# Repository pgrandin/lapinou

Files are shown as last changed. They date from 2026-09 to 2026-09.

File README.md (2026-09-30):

# Lapinou — side-view growth timelapse planter

Python-generated CadQuery assembly for a Raspberry Pi 3B+, provisionally using Camera Module 3 **standard**. The camera, Pi and provisional LED puck references are imported from STEP. The pot provides a **50.8 mm internal diameter × 76.2 mm usable depth** (2 × 3 inches). Default framing allows a **127 mm tall × 127 mm wide** plant (5 inches), with the camera level and 250 mm from the stem plane by default. Five indexed positions provide **230, 250, 270, 290 and 310 mm** camera-to-stem distances using the same printed parts.

This is a working prototype with printed parts and a tested 1.7 mm M2 camera pilot-hole coupon. The deployed camera runs on a **Pi 2 Model B Rev 1.1 with an IMX219 sensor and USB Wi-Fi**. The CAD electronics references still show a Pi 3B+ and Camera Module 3 standard; their full envelopes and optical framing have not been updated to match the deployed hardware. The Pi reference is a simplified community model; mounting-hole positions were checked against Raspberry Pi's official drawing.

## Quick start

```bash
git clone https://github.com/pgrandin/lapinou.git
cd lapinou
python3 -m http.server 8765 --directory viewer
```

Hosted on the homelab at http://lapinou.lab.lan (redeploy with `lab deploy . --name lapinou`; see `Dockerfile`).

Open http://localhost:8765/ for the assembly or http://localhost:8765/#bed for the print layouts. Current individual STEP/STL parts and viewer assets are included. The large complete `output/assembly.step` download is generated locally with the commands below; it is not committed. `output/printed_assembly.step` contains the printed parts only.

The minimal camera daemon and Frigate example are in `pi-camera/`. It serves a changing JPEG and archives a snapshot every six hours. See `pi-camera/README.md` for installation and service commands. No camera photographs, credentials, or printer upload scripts are included.

## Files

- Generator: `generate.py`
- Complete assembly, with imported electronics: `output/assembly.step`
- Printed parts in assembly positions: `output/printed_assembly.step`
- Eleven individual parts (nine original plus two light-mount additions), each as STEP and STL in print orientation: `output/print/`
- Actual CAD preview: `output/assembly.png`
- Geometry and mesh checks: `output/validation.json`
- Reference provenance: `references/SOURCES.md`

STEP preserves editable solids and assembly positions; the Python file is the parametric source. Do not slice the complete assembly: it includes electronics references, and the parts need separate print orientations.

## Regenerate

Interactive browser viewer: http://localhost:8765/

Direct print-bed view: http://localhost:8765/#bed.

Serve the viewer locally or on your LAN:

```bash
python3 -m http.server 8765 --bind 0.0.0.0 --directory viewer
```

The viewer includes orbit/pan/zoom, side/top views, five selectable camera distances, part visibility, an exploded view and STEP/STL downloads. The STEP download is the generated default 250 mm assembly; changing the viewer selector moves the displayed assembly only. Individual printed parts work at every position. Three.js 0.180.0 and its MIT licence are stored locally in the viewer's vendor directory; no CDN is needed at runtime. The viewer shares geometry between assembly and bed modes, batches renders to one per animation frame, and uses lightweight lighting with a capped pixel ratio. Only display meshes load at startup; full-detail print STLs download on request. Electronics display meshes are simplified to approximately 15,000 triangles where needed; the original STEP imports and manufactured geometry remain full detail. The generator also writes display meshes and a manifest to `output/web/`. Relative symlinks connect those files and downloads to the viewer. For an alternative generator output directory, update those links before serving it.

Browser smoke check (regenerate the full assembly STEP first; requires Node.js):

```bash
# Run from the repository root
npm install --prefix scratch/web-test playwright
./scratch/web-test/node_modules/.bin/playwright install chromium
NODE_PATH=./scratch/web-test/node_modules node viewer/smoke.cjs
```

```bash
# Run from the repository root
uv venv .venv --python 3.12
uv pip install --python .venv/bin/python -r requirements.txt
.venv/bin/python generate_puck.py
.venv/bin/python generate.py
```

Change framing, for example:

```bash
.venv/bin/python generate.py --plant-height 150 --plant-width 100 --distance 290 --output output-150mm
```

Dimensions are millimetres. The distance argument selects an assembly position from 230/250/270/290/310; it does not change the printed parts. Changing plant height changes the mast, ruler and light-arm geometry. Supported ranges are limited to what the two-piece base and ruler placement support. Changing the camera model requires adapting its STEP transformation, mounting pattern and field-of-view calculation. It is not interchangeable merely because a replacement STEP imports successfully.

## Mechanical design

| Part | Function |
| --- | --- |
| camera_base | Rigid rail, mast foot mounting and four 12 mm tall Pi supports |
| plant_base | Matching rail, pot platform and ruler support mounting |
| catch_tray | Drainage basin wrapping around the pot ears; blind fixing holes keep the floor closed |
| pot | 2.4 mm walls, 3.2 mm floor, five 3 mm drainage holes, and two retaining ears flush with the pot bottom |
| camera_mast | Flat camera plate with four bosses and ribbon tie slots |
| camera_shoe | Low socket bolted to the existing camera-base holes; clamps the camera plate |
| ruler_support | Flat plate connecting the ruler to its mounting shoe |
| ruler_shoe | Low open channel bolted to the existing plant-base holes |
| growth_ruler | Raised 5 mm graduations and bold 50 mm labels; two screws prevent rotation |
| light_arm | New flat-printing arm behind the ruler; uses its existing two holes |
| light_cradle | New annular puck seat with three washer retainers and clear LED opening |

The two base halves use an indexed lap with **40–120 mm overlap**, depending on position. The moving upper plate has six columns of 3.3 mm clearance holes at 20 mm pitch, in two rows. The fixed lower plate has four **2.6 mm pilot holes** for M3 screws driven directly into PLA. Use all four screws, from above, through two adjacent columns. Each engraved distance label lies between its selected columns. There are no nuts on this joint. The lower plate provides 4 mm of plastic thread engagement; the upper plate clears the screw so tightening clamps the two halves together. Two short screws retain the pot on the tray; two separate screws retain the tray on the base. The camera's four M2 holes use a 21 × 12.5 mm pattern taken from the imported STEP. The Pi's four M2.5 holes use the 58 × 49 mm pattern confirmed in the manufacturer drawing.

Both mounts now separate into a flat plate and a low shoe. The camera plate seats 24 mm into a socket, with 0.4 mm clearance in front and 0.2 mm at each side. The ruler support seats in a 24 mm deep open channel with 0.4 mm clearance in front. Two M3 × 12 mm screws per shoe pass through 3.3 mm clearances and grip 2.6 mm pilots in the plate, with nominal 4 mm thread engagement and no nuts. Tightening pulls each plate onto its rear datum. The camera lens, ruler face, soil zero and base mounting-hole positions remain at their previous coordinates. The ruler shoe has a narrow rear post to leave the foot nuts accessible.

Exposed edges are softened in the Python model:

- Main base and mast-foot corners: 3 mm radii with 0.5 mm perimeter bevels.
- Pot lip: 0.8 mm fillet; tray lip: 0.6 mm fillet; pot ears have 2 mm corner radii and 0.5 mm bevels.
- Flat plates and ruler: 1–1.5 mm corner radii, with 0.3–0.5 mm edge bevels. Shoe walls have 0.3–2 mm corner radii and 0.2–0.4 mm top bevels.
- Cable slots: 0.8 mm rounded corners and 0.3 mm entry/exit bevels.

Pot ears use 3.3 mm clearance holes and the tray uses 2.6 mm blind pilots. Other mounting holes retain their specified diameters: 3.4 mm for the remaining M3 printed-part joints, 2.8 mm for Pi M2.5 screws, with nuts. The four camera bosses now use 1.7 mm pilots for M2 screws biting directly into PLA, without nuts. Camera hole spacing remains 21 × 12.5 mm; the bosses and bracket outline are unchanged. Clamping surfaces stay planar and the base lap faces remain square. The ruler has a 2 mm margin below zero and its ticks start 1 mm in from the side to keep the raised markings supported behind the perimeter bevel. Its print footprint is now 134 × 24 mm, with the same 3.0 mm body and 0.8 mm relief.

The pot, tray and ruler move as one assembly when the distance changes. The Pi and camera stay together, so adjustment does not change the ribbon route. Remove the four joint screws, move the plant half to the selected holes, and tighten on a flat surface. Hole clearance and printer tolerance limit repositioning accuracy; check focus and recalibrate pixels/mm after changing distance. Keep the distance fixed during each timelapse.

The Pi mounts on the open, elevated platform at the camera end, approximately 200 mm away from the pot. Ports remain accessible. This is an indoor open carrier, not a sealed or splashproof enclosure. No HAT or heatsink is included in the clearance checks.

The pot bottom and its two retaining ears share the same flat underside at assembly Z = 14.4 mm. The ears print directly on the bed, with 6 mm thickness and rounded, bevelled edges. The tray wall follows around both ears with 0.6 mm clearance; its footprint is 80 × 104 mm. Four internal pads and two ear pads support the pot. Two M3 × 10 mm screws enter from above through the ears at Y = ±38 mm. Two more enter from below the base at the existing Y = ±44 mm holes. Each screw engages a separate 4.2 mm deep blind pilot in the tray, with a 2.2 mm closed end. Use no washer on these four screws; nominal engagement is 4 mm. Remove the top two screws to lift out the pot. Water in place during recordings to preserve registration. Check the printed tray for leaks before mounting powered electronics and avoid filling it high enough to submerge the pot floor.

## Hardware and assembly

Use button-head screws for the recessed underside locations; check actual head dimensions against the 6.6 mm diameter × 2 mm deep recesses. No heat-set inserts or printed threads are required.

| Fastener | Qty | Location |
| --- | ---: | --- |
| M3 × 8 mm self-tapping/thread-forming screw, no nut | 4 | Adjustable base lap; screws enter from above into PLA pilots |
| M3 × 16 mm button head, nut, washer | 8 | Camera and ruler shoe feet; from below |
| M3 × 12 mm self-tapping/thread-forming screw, no nut | 4 | Two per shoe, entering from the back into the flat plate |
| M3 × 10 mm self-tapping/thread-forming screw, no nut | 4 | Two below the base into the tray; two above the pot ears into separate tray pilots |
| M3 × 20 mm, nut, thin washer | 2 | Ruler + support + new light arm; replaces the original M3 × 12 screws |
| M3 × 10 mm self-tapping/thread-forming screw, no nut | 2 | Light cradle to arm |
| M3 × 6 mm self-tapping screw, 9 mm OD M3 washer | 3 | Puck rim retention |
| M2.5 × 25 mm button head, nut, nylon washer | 4 | Pi mounting posts; from below |
| M2 × 8 mm, small nylon washer, no nut | 4 | Camera; screws enter from the camera side and bite into 1.7 mm PLA pilots |

Print `output/print/m3_pilot_coupon.stl` in the same PLA and settings as the base first. It has labelled 2.5, 2.6 and 2.7 mm pilots through a 4 mm plate, matching the threaded lap thickness. Use the actual screws to find a firm fit without splitting or stripping. The default is 2.6 mm; change `JOINT_PILOT` in `generate.py` and regenerate if needed. The lap uses 8 mm screws with an 8 mm stack and no washer; check that the actual tip does not protrude below the base. A pointed tip gives less full-thread engagement. Tighten by hand; repeated removal can wear PLA threads. The mount clamps and blind tray fixings also use this pilot size; the remaining joints use the nuts listed above.

Dry-assemble before final tightening; screw lengths assume ordinary nuts and thin washers. Tighten PCB hardware gently. Fasteners, washers and the ribbon cable are described here but are not separate CAD objects.

For an M2 screw fit check before reprinting the camera plate, run `.venv/bin/python generate_camera_fit.py` after generating the assembly. This crops all four camera bosses directly from the print-oriented STEP, preserving the 1.7 mm pilots, 21 × 12.5 mm spacing, 7 mm backing and 4.38 mm bosses. The test piece is 20.5 × 29 mm and prints back down using the same settings as the full plate. Files: `output/print/camera_mount_fit.stl` and `output/print/camera_mount_fit.step`. Check screw grip and camera alignment on this piece before printing the full mount.

1. Select the 250 mm index initially and screw the two rails together on a flat surface using all four M3 screws from above. Bolt both mounting shoes to their existing base holes, seat the small pilot-hole ends of both flat plates fully on the shoe floors, then install two M3 × 12 mm clamp screws per shoe from behind. Use no washer under these clamp heads; the 12 mm length allows 4 mm nominal engagement after the 8 mm shoe wall.
2. Fit the Pi to its mounting posts and fit the camera to the mast's four front bosses, lens pointing at the pot. Insert the four M2 × 8 screws through small nylon washers and the camera PCB into the 1.7 mm PLA pilots. Tighten gently by hand. The pilot is a starting print fit; adjust `CAMERA_PILOT` in `generate.py` if the actual screws fit too tightly or loosely. An already printed bracket with 2.3 mm through-holes can still use the original M2 × 16 screws and nuts; direct PLA engagement requires the revised camera plate.
3. Route a **15-pin to 15-pin, 1 mm pitch CSI cable** from the camera, over the mast and down its back to the Pi. A 300 mm cable is a starting length; confirm the route with string and allow relaxed bends. The 200 mm stock cable may be short. Sleeve the cable where it is loosely restrained by ties; do not pinch its conductors or sharply fold it.
4. Attach the tray from below with two M3 × 10 mm screws, then seat the pot and secure its ears from above with two more M3 × 10 mm screws. Install the ruler with the raised markings toward the camera.
5. Fill soil to the small marks **3 mm below the rim**. The ruler's zero corresponds to that height. Lock the setup before recording.

## Printing

All exported STLs are translated to the bed and oriented individually. The plant base is **220 × 158 mm** and the camera base is **215 × 150 mm**. Both fit the MK3’s 250 × 210 mm bed with their long dimension along X. Allow for your printer's actual printable area and brim requirements.

Use **Bed** in the viewer to inspect five production plates and a separate pilot coupon test. It reuses lightweight display meshes with the same print rotations generated for the STL exports, excludes electronics, and provides Orbit/Side/Top views. The plate selector shows each part's XYZ dimensions, lower-left X/Y position in millimetres, and its STL download. Each layout leaves at least 5 mm at the bed edges and 10 mm between part bounding boxes, with Z = 0 at the bed and all parts below the MK3's 210 mm height limit. The grid is 10 mm; the dashed rectangle marks the 5 mm edge margin.

| Plate | Parts and orientation |
| --- | --- |
| 1 | Camera base, base down and Pi posts up |
| 2 | Plant base, top face down to support the long lap |
| 3 | Pot and tray upright; camera and ruler support plates flat; both low shoes base down |
| 4 | Ruler only, flat with markings up for the colour change |
| 5 | New light arm flat and puck cradle shelf down; existing prints reused |
| Test | Pilot coupon; print this before the bases |

For the default 5-inch plant, the camera plate prints **158.3 × 38 × 11.38 mm**, the ruler support **96.8 × 24 × 5 mm**, and the two shoes are **30 mm high**. The third plate now tops out at the pot’s 79.4 mm instead of the previous 164.3 mm camera mast. Actual print-time savings depend on slicing settings; no time estimate is claimed. A different plant height may require rearranging the plate; the viewer flags insufficient spacing.

These are layout previews, not sliced jobs. STL downloads remain individual parts at their own origins; use the displayed positions to reproduce a plate in PrusaSlicer. Add local supports and any brims in the slicer and inspect their clearance. Print the grouped parts by layer rather than sequentially completing each object. The colour change applies only to the ruler plate.

- PLA is the starting material for the self-tapping joint. Start with a 0.4 mm nozzle, 0.2 mm layers, 4–5 walls, 5–6 top/bottom layers and 30–40% infill. These are untested starting settings.
- Pot, tray, camera base and the two low shoes print base down. The camera plate prints back down with bosses facing up; the ruler support plate prints flat. The plant base prints upside down with its broad top and upper lap on the bed; this avoids a long unsupported tongue. Its engraved distance labels face the bed. The ruler prints flat, raised markings up.
- The pot ears lie flush with the bottom and print directly on the bed. The camera bosses grow upward from the flat plate. The low shoes have small horizontal clamp holes; inspect their bridges in the slicer. Keep supports out of small mounting holes.
- Check holes with the intended fasteners; small FDM holes may need careful cleanup. Verify the ruler's spacing with a physical ruler.
- The basin is not assumed watertight just because its mesh is closed. Leak-test it separately.

### Two-colour ruler on the MK3

The ruler is one connected solid: a **3.0 mm flat body** with **0.8 mm raised ticks and numbers**, for a total thickness of **3.8 mm**. All markings start at the same print height. Ticks are 0.8 mm wide; numbers use a larger, bold font for a 0.4 mm nozzle. The exported ruler STL already lies flat with the markings facing upward; no supports are needed.

1. Load `output/print/growth_ruler.stl` into PrusaSlicer, using the MK3 single-extruder profile.
2. Use 0.20 mm layers and a 0.20 mm first layer, without a raft or variable layer height.
3. In sliced Preview, add a colour change **before layer 16, displayed Z = 3.20 mm**. The body finishes at Z = 3.00 mm; layers 16–19 print only the raised markings in the second colour.
4. Use contrasting colours of the same material, for example a white PLA body and black PLA marks. Verify the layer preview shows only ticks/numbers after the change. The MK3 will prompt for the filament swap through M600.

For the installed PrusaSlicer Flatpak with the MK3 and Hatchbox PLA profiles, `python3 slice_ruler.py` creates the same 0.20 mm white-to-black G-code and verifies that M600 appears once before layer 16. It only slices; it does not contact a printer. Machine-specific G-code is kept out of Git.

For other layer heights, select the first layer containing only markings, immediately after the 3.0 mm body. STL and STEP do not store an M600 command; add the change in the slicer before exporting G-code. Print the ruler on its own if other parts should retain their original colour.

Prusa's colour-change instructions: https://help.prusa3d.com/article/color-change_1687

## Measurement and framing

The camera looks horizontally along the base. Its lens centre is **154.3 mm above the base underside**, halfway up the intended 127 mm growth range above the 90.8 mm soil datum. The ruler body face lies at the stem plane; its markings project 0.8 mm toward the camera. The ruler sits beside the plant.

The 230 mm setting is useful for smaller plants but may crop the full 5-inch target at its near edge. Start at 250 mm for the intended mature envelope; the more distant settings add framing room.

Using the standard camera's nominal 41° vertical FoV, the model calculates about **187 mm vertical coverage** at the 250 mm stem plane, and **139 mm** at the near edge of a 127 mm deep plant envelope. This assumes full sensor framing. Cropping, capture mode, lens distortion and focus breathing can change the actual image; verify framing with a ruler in a live capture.

For repeatable apparent height, keep the stem near the calibrated plane, use a plain background and consistent lighting, and calibrate pixels/mm from the scale in the captured image. Leaves extending toward the camera appear larger; one side view measures projected growth, not true 3D size. Establish focus once and lock it for the sequence. Fixed exposure and white balance also help under controlled lighting.

Camera controls and capture details:

https://www.raspberrypi.com/documentation/computers/camera_software.html

## Validation

The generator checks mounting-hole coordinates in both imported STEP files, valid connected solids for every printed part, 220 mm bed bounds, volumetric interference between printed parts and electronics, and boundary/non-manifold edges in the eleven assembly STLs. It checks that both pot-ear undersides are flush with the bottom, that the retaining holes remain open, and that the staggered tray pilots have closed 2.2 mm ends and screw-head clearance. It also verifies the flat plates’ print heights and broad bed contact, clamp-hole alignment and surrounding material, and tool/nut access above the shoe feet. At each of the five distance settings it also checks base interference, pilot/clearance alignment, screw-head space, bearing material and minimum lap overlap. Results and reference file SHA-256 hashes are saved with each build.

These checks do not establish real-world stiffness, printer tolerance, cable flex, fastener clearance, optical calibration, thermal performance or water tightness. Verify those on the prototype.

## Bolt-on LED puck mount

The light adds **two printed parts**, `light_arm` and `light_cradle`. All nine previously printed parts retain their geometry. Plate 5 in the bed viewer contains only the new parts; the arm prints flat (153.7 × 72 × 8 mm) and the cradle prints shelf down (73.3 × 106.65 × 6.5 mm). Both fit together on the MK3 bed. The arm's small transverse pilot holes may bridge slightly; keep supports out of them.

The arm seats against the back of the existing ruler support at X = pot centre + 8 mm and uses its two existing M3 through-holes, 10 mm apart. Replace the two M3 × 12 ruler screws with **two M3 × 20**, reusing the nuts and thin washers. The combined ruler/support/arm stack is 16 mm. Fit the new arm one screw at a time to preserve the ruler position, then verify the zero mark against the soil line.

Fasten the cradle onto the arm with **two M3 × 10 self-tapping screws** through 3.3 mm clearances into 2.6 mm pilots (4 mm cradle + 6 mm engagement; no washers). Seat the puck LED-side down. Retain its rim with **three M3 × 6 screws and 9 mm OD M3 washers**, tightened gently; the washers overlap the disc edge. The cradle supports the outer 2 mm of the disc and leaves the LED packages, vent holes, centre retaining nub and top USB-C connector clear. No adhesive or changes to the old parts are required.

At the default 127 mm plant height, the LEDs are 157 mm above the soil, giving 30 mm over the intended canopy. The arm stands beside the plant and behind the ruler; the beam stays above the target plant envelope. All light components move with the pot when camera distance changes. Route the USB lead along the arm with slack at the puck so cable tension does not twist the ruler support. This is a geometric placement, not a measured light-output recommendation.

The puck is imported from `output/led-puck/yaungel_puck_reference.step`. Its outside diameter is measured at 59.3 mm; other dimensions remain provisional. The cradle pocket is 59.5 mm diameter (0.1 mm radial clearance). Disc thickness still needs measurement before finalizing the cradle. This diameter update leaves the long arm and all nine original printed parts unchanged. To revise it, update `references/yaungel-led-puck/parameters.json`, run `.venv/bin/python generate_puck.py`, then `.venv/bin/python generate.py`. The standalone puck model is a reference asset, not a printed part.

New part exports:
- `output/print/light_arm.stl`
- `output/print/light_arm.step`
- `output/print/light_cradle.stl`
- `output/print/light_cradle.step`

Assembly: http://localhost:8765/
Bed view (select plate 5): http://localhost:8765/#bed

The generator checks the reused hole alignment, cradle pilots, washer contact on both puck and cradle, flat arm orientation, plant-envelope clearance, and interference with existing geometry. These are CAD checks; mechanical stiffness and the actual puck fit remain untested.

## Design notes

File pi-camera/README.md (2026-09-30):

# Pi camera daemon

One Python standard-library daemon plus the already installed `rpicam-still`. It keeps the camera open, captures a 1640 × 1232 JPEG about every two seconds, and serves the latest complete image at:

http://192.168.1.150:8080/snapshot.jpg

The first fresh frame is archived immediately, then one every six hours, in `/home/pi/lapinou/snapshots/` on the Pi. Names contain UTC timestamps. Restarting retains the six-hour schedule using the last archived file's modification time. Archives are kept until manually removed; there is no automatic deletion. Frequent preview images rotate through three files in `/run/lapinou-camera/` (RAM), so they do not continually write to the SD card. A stalled or exited camera causes a service restart; the HTTP endpoint returns 503 for missing or stale frames.

## Frigate

Merge `pi-camera/frigate.yaml` into the existing Frigate configuration. It polls the JPEG at 1 fps using `preset-http-jpeg-generic`, with object detection and video recording disabled. The image itself updates about every two seconds. The six-hour archive is independent of Frigate and continues if Frigate is offline. No Frigate server configuration has been changed automatically.

Frigate documents changing JPEG inputs here: https://docs.frigate.video/configuration/camera_specific/#jpeg-stream-cameras

To enable continuous Frigate video recording later, JPEG input requires encoding; see the same documentation. This setup stores stills locally and does not provide RTSP or audio.

The address `192.168.1.150` is the example deployment; substitute your Pi's address in these commands and `frigate.yaml`.

## Install / manage

The files are deployed to `/home/pi/lapinou/camera.py` and `/etc/systemd/system/lapinou-camera.service` on `pi@192.168.1.150`.

```sh
ssh pi@192.168.1.150 'mkdir -p /home/pi/lapinou'
scp pi-camera/camera.py pi-camera/lapinou-camera.service pi@192.168.1.150:/home/pi/lapinou/
ssh pi@192.168.1.150 'sudo install -m 644 /home/pi/lapinou/lapinou-camera.service /etc/systemd/system/lapinou-camera.service && sudo systemctl daemon-reload && sudo systemctl enable --now lapinou-camera'
ssh pi@192.168.1.150 'systemctl status lapinou-camera --no-pager'
ssh pi@192.168.1.150 'journalctl -u lapinou-camera -n 30 --no-pager'
```

Use `sudo systemctl restart lapinou-camera` after changes, or `sudo systemctl disable --now lapinou-camera` to stop it and disable boot startup. The systemd unit exposes `WIDTH`, `HEIGHT`, `PORT`, `SNAPSHOT_DIR`, and `SNAPSHOT_SECONDS` as environment settings. Exposure and white balance currently remain automatic.

## Checks

```sh
python3 pi-camera/test_camera.py
curl --fail http://192.168.1.150:8080/snapshot.jpg -o camera-live.jpg
```

The local test covers JPEG responses, missing/stale frames, cache headers, atomic archive writes, and preserving archive cadence across restarts. Deployment is additionally checked with actual camera frames, FFmpeg's JPEG input options, an accelerated four-second archive schedule in a separate test directory, and systemd restart behavior.

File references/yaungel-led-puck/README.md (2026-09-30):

# YAUNGEL LED puck — provisional reference

A photo-derived clearance/reference model, not a manufacturer CAD asset or a functional printable light. The user measured the outside disc diameter at **59.3 mm** on 2026-09-30. All other dimensions remain estimates.

Edit `parameters.json` here and run `.venv/bin/python generate_puck.py` from the project root. The STEP, reference STL, display meshes and metadata are written to `output/led-puck/`. The STEP is imported into the planter assembly as a reference; the puck itself is not a printed part.

Coordinates: disc underside Z=0; LED faces point down; USB-C socket faces up. The disc is 59.3 mm diameter and 2.5 mm thick, the socket projects 7 mm above the disc, and the retaining nub projects 2 mm below it. Total estimated height is 11.5 mm. Four 9 mm vents lie on a 31 mm pitch circle at 45°, 135°, 225°, 315°. Grip ribs are 4.5 mm high. All these dimensions are independent parameters; changing diameter does not silently scale the connector or other features.

Visible photo features represented: green circular disc, four vent holes, cross-shaped top grips, central vertical USB-C shell/tongue, underside centre retaining nub, four groups of four LED packages. USB contacts, hidden wiring, internal electronics, mould details, real clip geometry and exact LED types/colours are omitted or schematic. The retaining nub is especially uncertain. This model is not suitable for final fit tolerances until measured.

Measurement priorities:
1. Disc thickness at its rim (outside diameter measured: 59.3 mm).
2. Overall height, and USB-C socket height above the disc.
3. Vent hole diameter and centre-to-centre distance across opposite holes.
4. Retaining nub diameter, projection and any undercut.
5. Grip-rib height/span and connector position relative to disc centre.

Source listing: https://www.amazon.com/dp/B0BHNNJ1K2
Connector and LED close-up: https://m.media-amazon.com/images/I/61aK2QrFHrL.jpg
Top grip/vent view: https://m.media-amazon.com/images/I/7129iy2fuTL.jpg
Components: https://m.media-amazon.com/images/I/71RNoWx2ldL.jpg

Local preview: http://localhost:8765/puck.html

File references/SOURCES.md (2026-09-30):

# Imported STEP references

Retrieved 2026-09-29. The generator imports the two electronics STEP files below, plus the photo-derived LED puck generated by `generate_puck.py`. Unused Pi 5 and camera-wide research downloads are excluded from this repository.

## Raspberry Pi 3 Model B+

Author: Anson Biggs / MisterBiggs. Simplified reference solid, MIT licence; the downloaded licence is retained in `references/raspberry-pi-3b-plus/LICENSE`.

Creator's project:

https://gitlab.com/MisterBiggs/MyModels/tree/master/Rough%20Pi%20Model

Pinned STEP download used:

https://gitlab.com/MisterBiggs/MyModels/raw/0e57323325c75e175542afb2fc1963708e6ec549/Rough%20Pi%20Model/Rough%20Pi%20Model.step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

Local file:

references/raspberry-pi-3b-plus/raspberry-pi-3b-plus.step

The source coordinate system has PCB width along X, thickness along Y and length along Z. Mounting-hole axes are at X = 3.5/52.5 and Z = 23.5/81.5 mm, diameter 2.75 mm. The generator rotates and translates this solid without scaling.

Official drawing used to verify the 85 × 56 mm board outline and 58 × 49 mm mounting pattern:

https://datasheets.raspberrypi.com/rpi3/raspberry-pi-3-b-plus-mechanical-drawing.pdf

https://pip.raspberrypi.com/categories/532

## Camera Module 3 standard

Publisher: Raspberry Pi. The imported standard model is retained from the original manufacturer archive; this project's code does not relicense the reference model.

https://pip.raspberrypi.com/categories/1207-design-files

https://pip-assets.raspberrypi.com/categories/1207-design-files/documents/RP-008154-DS-1-camera-module-3-step.zip

Local imported file:

references/camera-module-3-step/Camera_module_3_std_model_simple.stp

The source PCB has mounting holes at X = 2/14.5 and Y = 2/23 mm, diameter 2.2 mm. The lens points along negative Z. The assembly rotates this direction to positive X and places the model's front lens extremity at X = 0. This is a mechanical distance datum, not a measured optical principal plane. No scaling is applied.

Mechanical drawing and FoV reference:

https://datasheets.raspberrypi.com/camera/camera-module-3-standard-mechanical-drawing.pdf

https://www.raspberrypi.com/products/camera-module-3/

## CAD tooling

CadQuery 2.6.1 imports both models using `cq.importers.importStep` and exports true STEP solids and a named assembly. No electronics meshes are converted to STEP.

https://cadquery.readthedocs.io/en/latest/importexport.html

## LED puck

Photo-derived reference generated from `references/yaungel-led-puck/parameters.json`. Disc diameter measured at 59.3 mm; other dimensions remain provisional. Provenance is documented in `references/yaungel-led-puck/README.md`.

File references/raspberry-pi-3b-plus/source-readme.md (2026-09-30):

## Summary

A rough, blocky, minimal, but dimensional correct model of a [Raspberry Pi 3 Model B+](https://amzn.to/2AI34wa). I use this to quickly measure parts of the Pi whenever I'm working on a Pi-related project in CAD. I included the **.f3d** file which should work best since the model was designed in Fusion, but I also included a **.step** file for use in every other CAD software, as far as I know, feel free to ask for a different file type.

## Printing

**I don't see any reason in printing this but you do you.**

## Download

[Get this model on my Thingiverse](https://www.thingiverse.com/thing:3011653)
[Get this Project on my Gitlab](https://gitlab.com/MisterBiggs/MyModels/tree/master/Rough%20Pi%20Model)
[Get this Project on my Blog](http://blog.ansonbiggs.com/rough-raspberry-pi-model/)

[Direct Download .stl](http://bit.ly/RoughRaspstl)  
[Direct Download .step](http://bit.ly/RoughRaspstep)  
[Direct Download .f3d](http://bit.ly/RoughRaspf3d)  

## Pictures

Dimension-Pi

Green-Pi

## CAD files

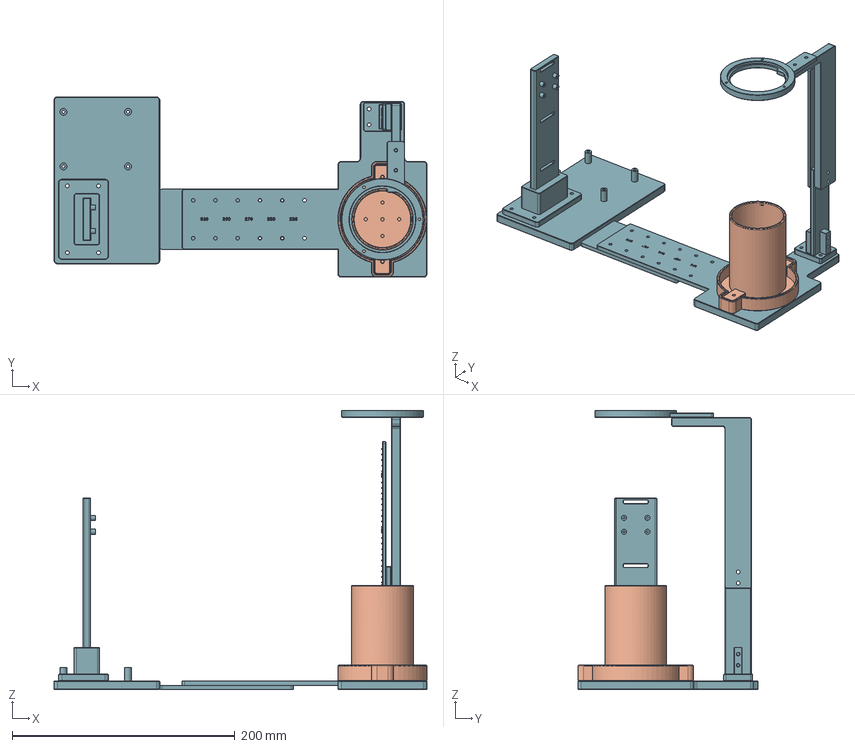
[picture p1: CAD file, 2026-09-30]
output/printed_assembly.step
335.0 x 162.0 x 251.0 mm
camera_base
plant_base
catch_tray
pot
camera_shoe
camera_mast
ruler_shoe
ruler_support
growth_ruler
light_arm
light_cradle

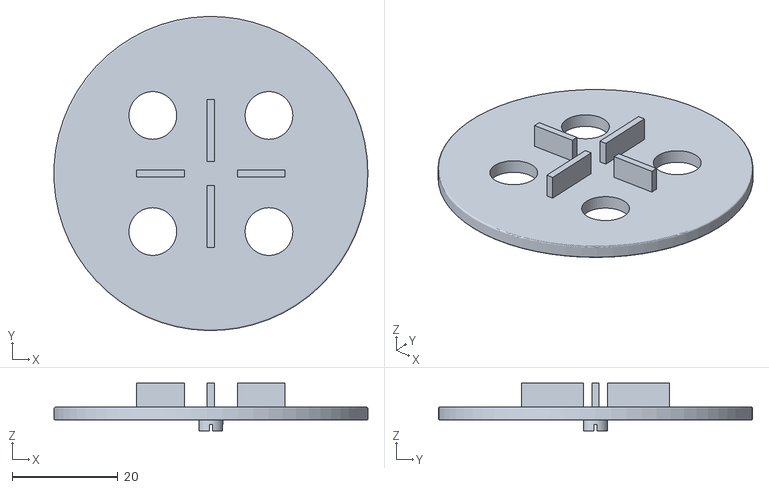
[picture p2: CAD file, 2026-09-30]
output/led-puck/green_body.stl
59.3 x 59.3 x 9.00

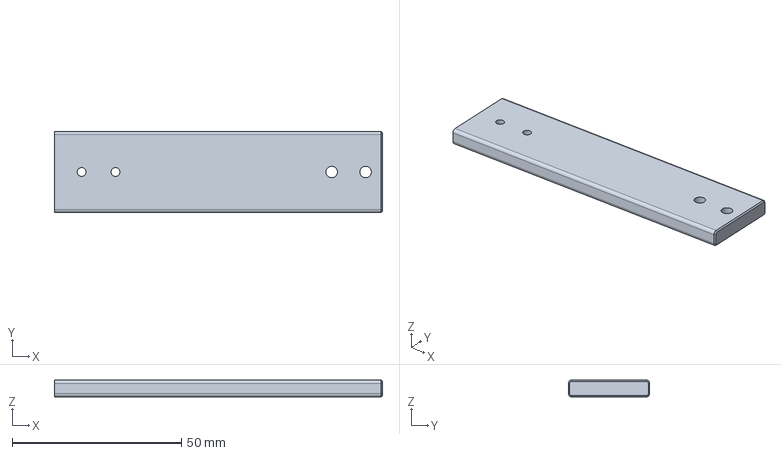
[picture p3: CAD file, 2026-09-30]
output/print/ruler_support.step
96.8 x 24.0 x 5.00 mm

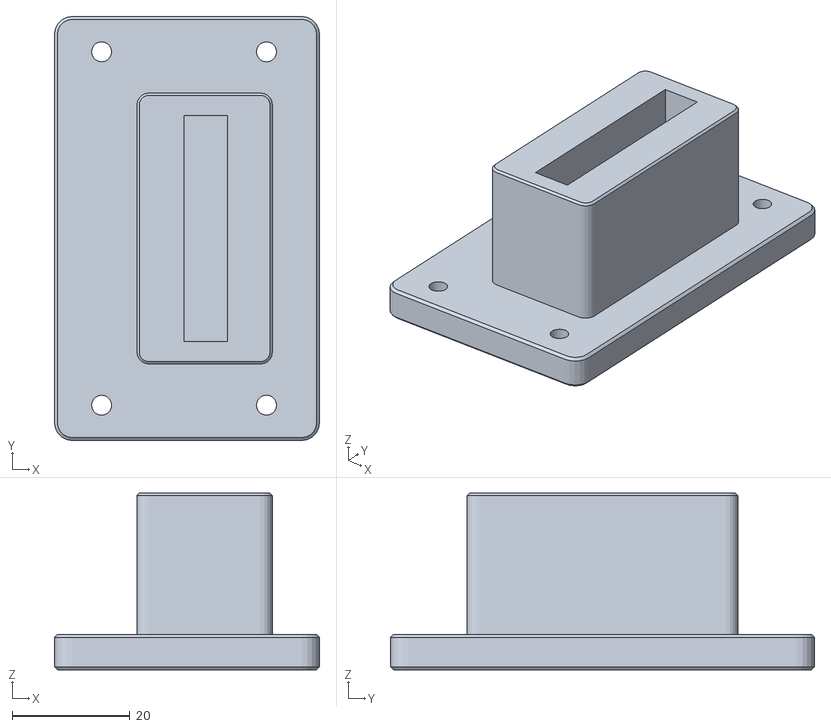
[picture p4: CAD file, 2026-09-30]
output/web/assets/camera_shoe.stl
45.0 x 72.0 x 30.0

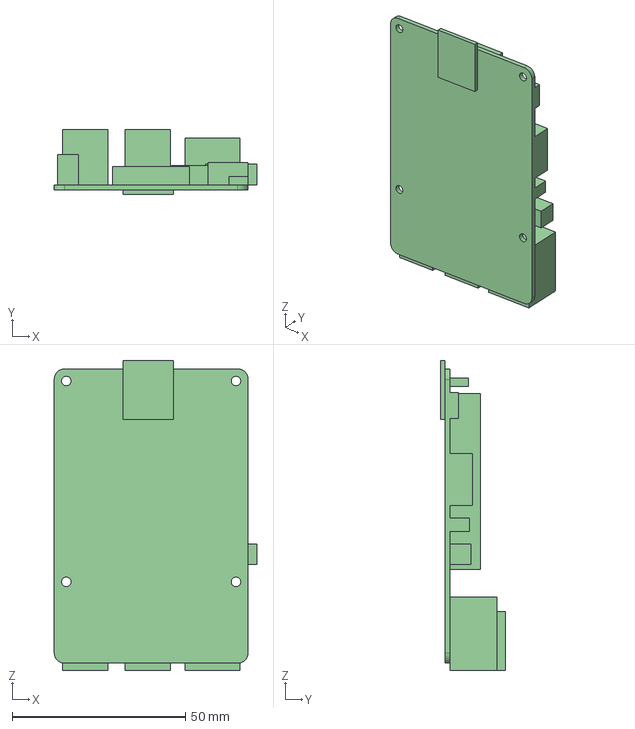
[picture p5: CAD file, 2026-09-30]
references/raspberry-pi-3b-plus/raspberry-pi-3b-plus.step
58.5 x 18.9 x 89.5 mm

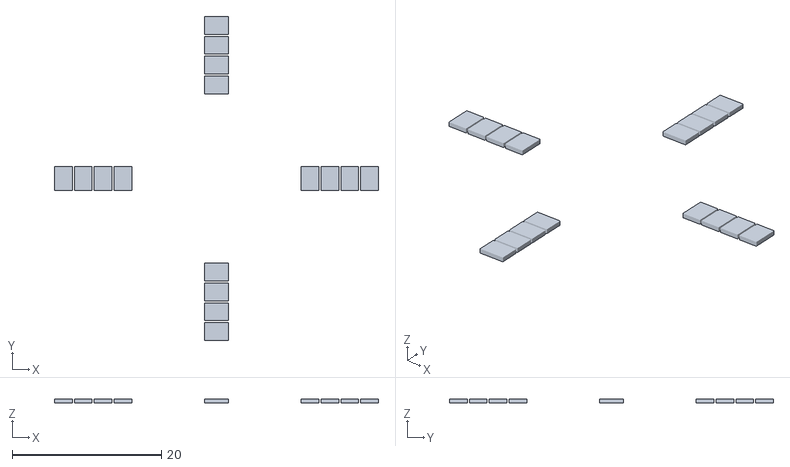
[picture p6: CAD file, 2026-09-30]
output/led-puck/led_packages.stl
43.3 x 43.3 x 0.55

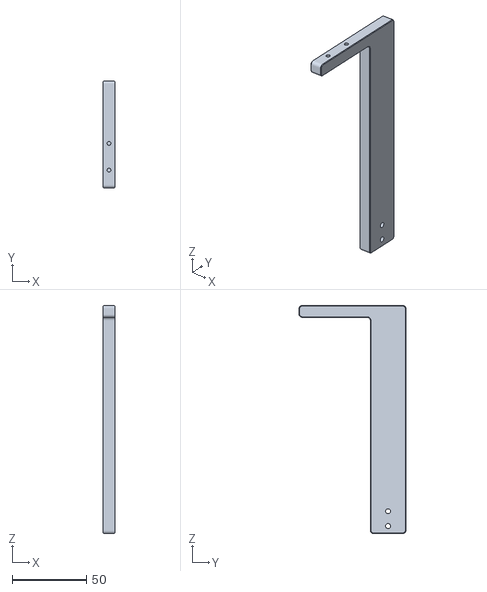
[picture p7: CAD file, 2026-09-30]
output/web/assets/light_arm.stl
8.00 x 72.0 x 153.7

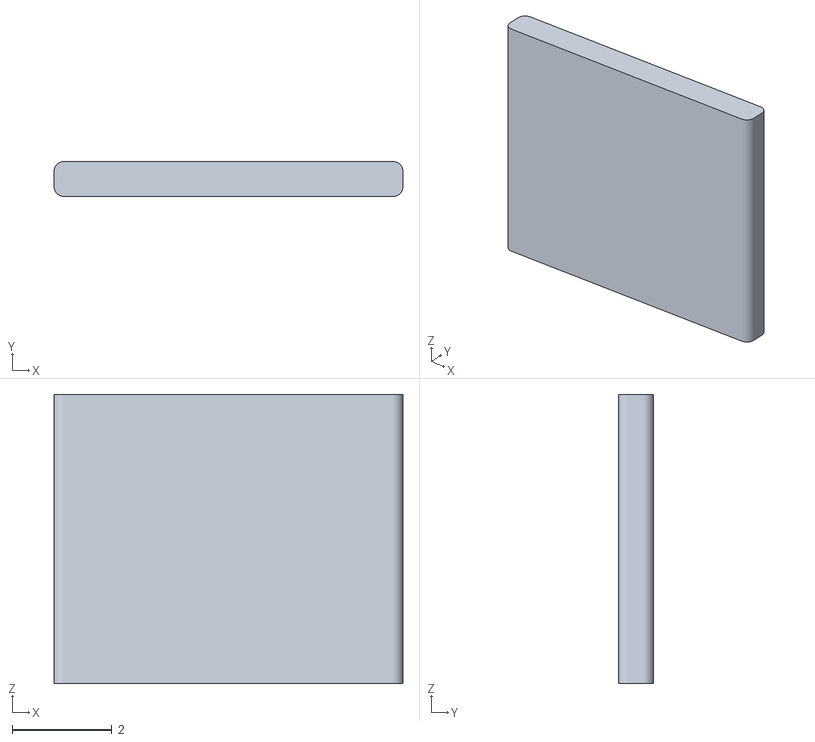
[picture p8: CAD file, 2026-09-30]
output/led-puck/usb_c_tongue.stl
7.00 x 0.7 x 5.80

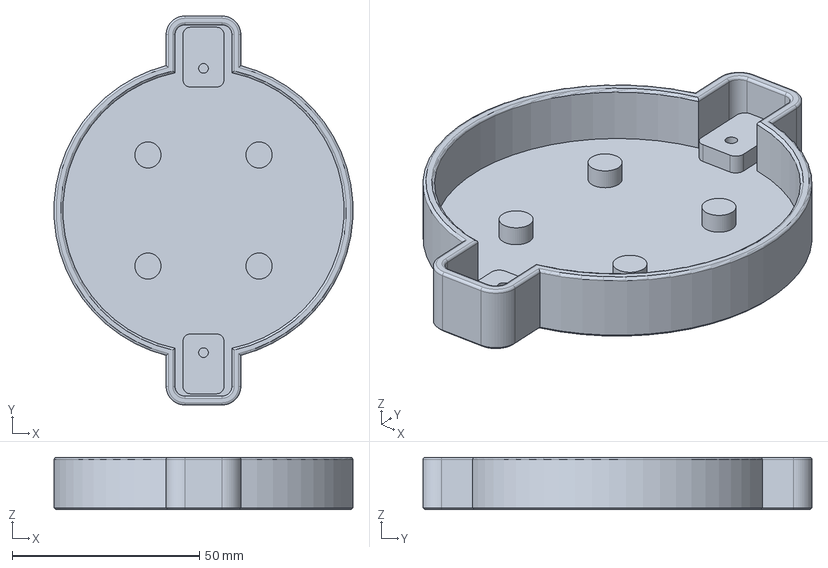
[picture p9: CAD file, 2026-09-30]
output/print/catch_tray.step
79.9 x 104.0 x 14.0 mm

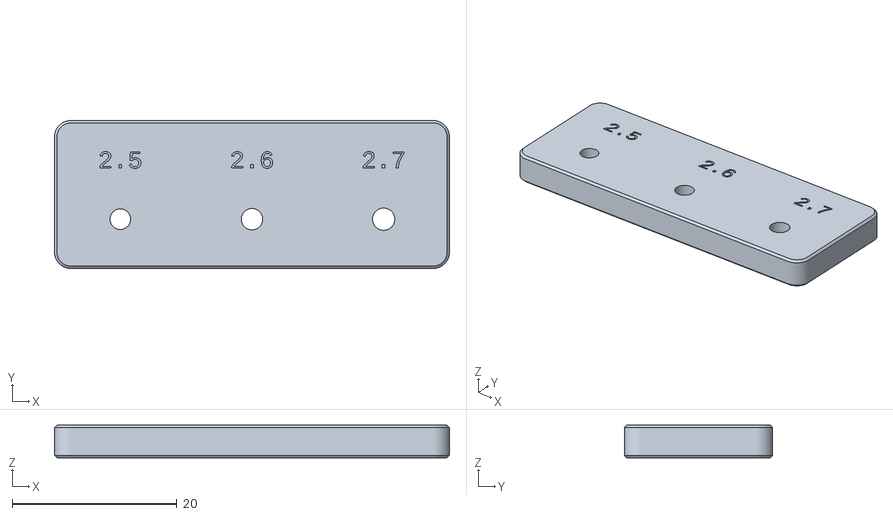
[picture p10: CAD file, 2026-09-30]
output/web/assets/m3_pilot_coupon.stl
48.0 x 18.0 x 4.00

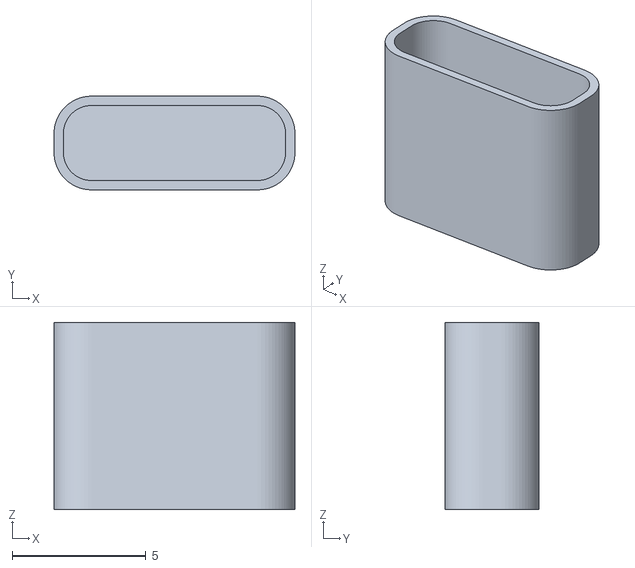
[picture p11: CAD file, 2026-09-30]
output/led-puck/usb_c_shell.stl
9.00 x 3.50 x 7.00

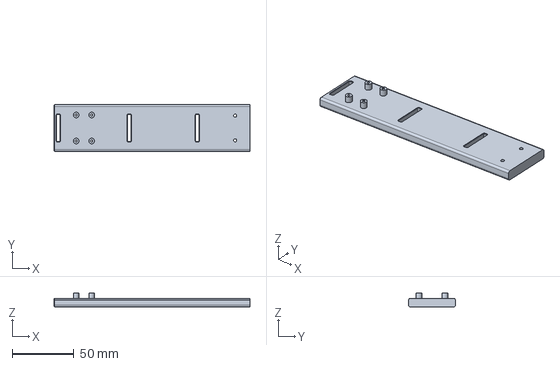
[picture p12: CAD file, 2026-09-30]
output/print/camera_mast.step
158.3 x 38.0 x 11.4 mm

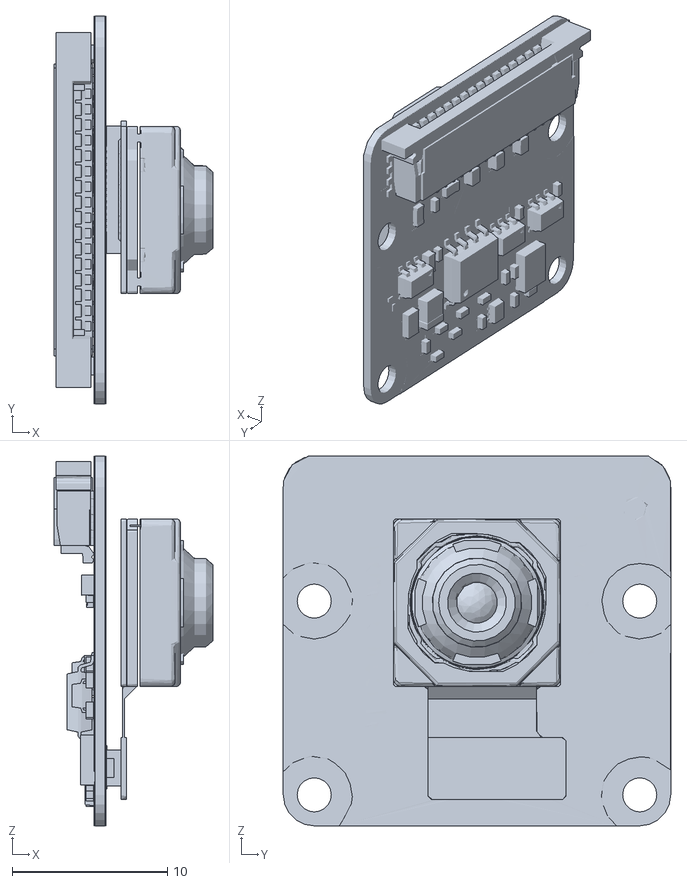
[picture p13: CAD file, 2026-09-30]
output/web/assets/camera_module_3_standard_REFERENCE.stl
10.2 x 25.0 x 23.9

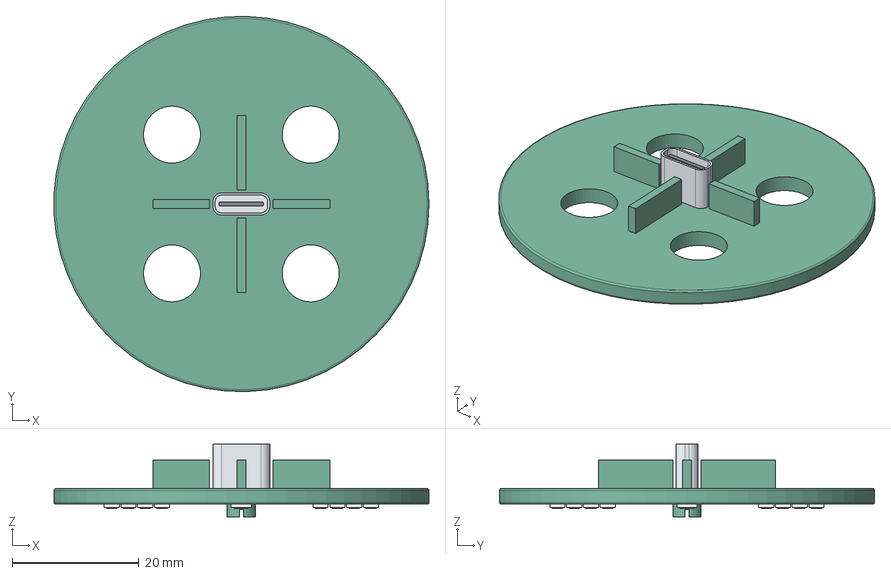
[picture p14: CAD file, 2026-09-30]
output/led-puck/yaungel_puck_reference.step
59.3 x 59.3 x 11.5 mm
green_body
usb_c_shell
usb_c_tongue
led_packages
warm_white_emitters
red_emitters
blue_emitters

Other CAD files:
viewer/assembly.step
output/print/camera_shoe.step
output/print/light_arm.step
output/web/assets/plant_base.stl
output/led-puck/blue_emitters.stl
output/led-puck/red_emitters.stl
output/led-puck/warm_white_emitters.stl
output/led-puck/yaungel_puck_reference.stl
output/print/camera_base.step
output/print/camera_base.stl
output/print/camera_mast.stl
output/print/camera_mount_fit.step
output/print/camera_mount_fit.stl
output/print/camera_shoe.stl
output/print/catch_tray.stl
output/print/growth_ruler.step
output/print/growth_ruler.stl
output/print/light_arm.stl
output/print/light_cradle.step
output/print/light_cradle.stl
output/print/m3_pilot_coupon.step
output/print/m3_pilot_coupon.stl
output/print/plant_base.step
output/print/plant_base.stl
output/print/pot.step
output/print/pot.stl
output/print/ruler_shoe.step
output/print/ruler_shoe.stl
output/print/ruler_support.stl
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

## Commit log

2026-09-30 Add printable timelapse planter, CAD viewer, and Pi camera daemon
    [assembly.step, blue_emitters.stl, camera_base.step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]
2026-09-30 Add Dockerfile to host the CAD viewer on lab.lan
